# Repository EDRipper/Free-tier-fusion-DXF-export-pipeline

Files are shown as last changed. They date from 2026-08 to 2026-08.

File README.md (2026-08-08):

# Free-tier Fusion DXF export pipeline

Turn a Fusion 360 **Personal** design into **scaled, hole-corrected, nested, laser-ready cut sheets +
a BOM** — precisely and reproducibly — even though Fusion Personal won't export DXF from the File menu.

Strandbeest walking — Fusion motion study

*The mechanism this pipeline cuts parts for — gear-driven, three leg-racks phased 120° apart, one hand
crank. ([full-res MP4](video/beest_walk.mp4))*

---

## Why this exists — the Strandbeest workshop

This drives a real event: a **2-day hackathon in The Hague** where **30 people (six teams of five)**
each build a **waist-height, hand-cranked walking [Strandbeest](https://en.wikipedia.org/wiki/Jansen%27s_linkage)**
out of flat-cut plywood.

The animation above is the Fusion 360 model. The catch: it's designed at desktop scale with 4 mm
holes, and **Fusion Personal can't export DXF from the menu.** To turn one CAD model into six cuttable
kits you have to:

1. get every flat part out of Fusion as a precise DXF (Fusion Personal *can* do this via the sketch/API — this automates it),
2. **scale** the whole thing up to ~1 m,
3. resize each hole to a **real bearing/rod** — *not* by scaling it (a 4 mm hole must become a **13 mm
   bearing seat**, not a 24 mm one), but by setting it to the hardware size,
4. **nest** the parts onto plywood sheets and **label** each one,
5. spit out a **shopping list**.

That's this repo, end to end. Everything is Snijlab-ready (cut on [Snijlab](https://snijlab.nl):
blue = cut, red = engrave, 1200×1200 mm, DXF R2004, kerf-compensated).

**One complete beest** (start here) → [`nested_1kit/`](nested_1kit): three sheets,
[sheet_01](nested_1kit/sheet_01.dxf) · [sheet_02](nested_1kit/sheet_02.dxf) · [sheet_03](nested_1kit/sheet_03.dxf).

**All six kits** → [`output/demo/`](output/demo): 13 laser-ready sheets + a
[BOM with purchase links](output/demo/BOM.md). Read [`BUILD_RISKS.md`](BUILD_RISKS.md) before cutting.

### How the beest maps to the pipeline
| | |
|---|---|
| **Legs** | 6 (three racks × mirror pairs) → 8 unique links, 6 of each per kit |
| **Drive** | 3:4 reduction (12T pinion → 16T driven), crank pins phased 120°, hand-cranked |
| **Pivots** | M6 bolt through an **F686** bearing in every rotating link hole (13 mm seat), nyloc-capped |
| **Crankshaft** | **12 mm rod in 6001 bearings** (28 mm seats), supported at each rack level |
| **Scale** | ×6 → ~waist height; holes fixed to hardware (13 / 28 / 12 / 6 mm), independent of scale |

---

## What the pipeline does
**Stage A** (inside Fusion) — projects each flat component's face to a DXF at true 1:1 mm + a parts
manifest. **Stages B–D** (`pack_dxf.py`) — scale to build size, set each hole to its real hardware
diameter (only the 4 mm through-holes are treated as holes, so intentional larger holes survive),
nest all copies onto sheets with rectpack, etch each part's name on a `LABEL` layer, and write the BOM.
Geometry is never redrawn — only exact affine transforms — so fits are preserved.

## Setup (once)
```bash
py -m pip install ezdxf rectpack
```

## Run
```bash
# Stage A — inside Fusion: Utilities > ADD-INS > Scripts > run fusion_export_dxf.py
#   -> parts_raw/<part>.dxf (1:1 mm) + parts_raw/parts_manifest.csv

# Stages B-D:
py pack_dxf.py            # -> nested/sheet_XX.dxf + BOM.csv (+ BOM.md by hand)
```
No Fusion? `py make_test_parts.py && py pack_dxf.py` runs it on synthetic parts.

## Configure — `config.json`
| key | meaning |
|---|---|
| `scale` | master build scale = `target_leg_mm / current_leg_mm`. Applied to geometry only. |
| `kits` | how many kits to nest (6). |
| `sheet_w_mm`, `sheet_h_mm` | sheet size (2440×1220 = full NL berken-multiplex sheet). |
| `default_hole_mm` | size every through-hole becomes unless overridden (13 = F686 pivot). **Not scaled.** |
| `hole_source_dia_mm` | only circles this size (4 mm) are treated as holes; bigger circles are left as outline. |
| `part_hole_overrides` | per-part hole size; per-hole roles go in `parts_raw/hole_roles.csv` (part,cx,cy,dia). |
| `hardware_per_kit` | fastener counts → the BOM ×kits. |

## The key idea: size and holes are decoupled
- **Scale** stretches link *lengths* to make the beest big.
- **Hole diameters** are fixed to real hardware and are **never** scaled — a 13 mm bearing seat stays
  13 mm whether the beest is knee- or waist-height. `hole_roles.csv` assigns bearing vs friction per hole.

## After nesting
- Sheets are Snijlab-ready: **blue** (layer `cut`, RGB 0,0,255) = cut through, **red** (layer
  `line engraving`, RGB 255,0,0) = engrave. Check the uploader preview matches before paying.
- Push `parts_processed/*.dxf` through **Deepnest** for tighter true-shape nesting if you want fewer sheets.
- **Cut a fit-test coupon + one prototype beest first** to dial in kerf before committing all kits.

## Files
- `fusion_export_dxf.py` — Stage A (runs in Fusion). · `fusion_walk_frames.py` — captures the walk animation.
- `pack_dxf.py` — Stages B–D. · `config.json` / `parts_raw/hole_roles.csv` — the knobs.
- `output/demo/` — final sheets + BOM. · `input/demo/parts_raw/` — the real extracted parts.

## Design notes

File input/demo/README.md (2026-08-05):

# Demo input

Two forms of the strandbeest input:

- **`parts_raw/`** — the **12 real flat parts** exported from Fusion by `fusion_export_dxf.py`
  (Stage A): 8 leg links, 2 gears, 2 spacer plates, each a clean 1:1 mm outline + holes, plus
  `parts_manifest.csv`. **This is the directly runnable pipeline input** — point `config.json`'s
  `parts_dir` at it and run `py ../../pack_dxf.py` to reproduce the sheets in
  [`../../output/demo`](../../output/demo).

- **`beest-fusion-cache-backup.zip`** — the upstream Fusion source (assembly + all component
  `.f3d` cache files) the parts were exported from. Archival; raw cache files don't open standalone
  (a `.f3z` export is the portable format). Open the design in Fusion and run Stage A to regenerate
  `parts_raw/` yourself.

Round hardware (rods, pins, bearings, the crank) is intentionally **not** here — those are bought,
not cut.

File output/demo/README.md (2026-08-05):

# Demo output — real nested cut sheets + BOM

Generated by the pipeline from the **real** strandbeest parts in
[`../../input/demo/parts_raw`](../../input/demo/parts_raw):

- `sheet_01.dxf … sheet_09.dxf` — the nested cut sheets (2440×1220 mm), ready for a laser/CNC.
- `sheet_01.svg … sheet_09.svg` — the same, rendered for quick viewing.
- `BOM.csv` — cut-part quantities (×10 kits) + hardware list.

**How it was made:**
```bash
py pack_dxf.py     # with config.json: scale 6.0, 10 kits, 2440x1220 sheets
```
590 parts (12 unique × 10 kits) nested onto 9 sheets. Holes reset to real hardware sizes —
**6.5 mm** pivots and **8 mm** gear bores — independently of the ×6 scale.

The `scale: 6.0` here is a representative value (~hip-height beest). Set it to
`target_leg_mm / current_leg_mm` for your final build size and re-run.

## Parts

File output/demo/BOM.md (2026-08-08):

# Bill of Materials — 6 strandbeest kits

Uniform **8 mm** hardware system: **two hole sizes only** — 22 mm (608 bearing seat) and 8 mm
(M8 rod / friction). Prices are rough EUR estimates; per-kit × 6. Links are Amazon.nl searches (NL).

## Cut parts
13 unique parts, nested onto **13 sheets** of **9 mm birch plywood** (berken multiplex,
**1200×1200 mm** — Snijlab's birch stock size). DXFs: `sheet_01.dxf … sheet_13.dxf`, already
Snijlab-ready: **cut = blue** (layer `cut`, RGB 0,0,255), **engrave = red** (layer `line engraving`,
RGB 255,0,0), text converted to outlines, DXF R2004, mm. One whole beest spans ~3 sheets:
`../nested_1kit/`.

| Item | Qty | Source |
|---|---|---|
| 9 mm birch plywood, 1200×1200 sheet | 13 | [Snijlab birch ply (supplies + laser-cuts)](https://snijlab.nl/en/products/birch-plywood) · [GAMMA berken multiplex](https://www.gamma.nl/assortiment/zoeken?text=berken%20multiplex) |

## Hardware

Bearings are used **only on the crankshaft** (where continuous rotation earns them). Leg pivots are
plain **M8 bolt + nylon washers** running in 9 mm clearance holes — the friction math shows this is
easily hand-crankable (~0.4 kgf at the crank), and it avoids the "bearing works loose in plywood"
problem. This drops bearings from 606 to **30** — see `../BUILD_RISKS.md` (R4).

| Item | Size | Per kit | ×6 | ~€ total | Buy |
|---|---|---|---|---|---|
| **608ZZ** bearing — crankshaft supports only | 8×22×7 mm | 5 | **30** | ~€14 | [amazon.nl](https://www.amazon.nl/s?k=608zz+lager) |
| **M8 bolts** — leg pivot pins (links pivot on the shank) | 30–50 mm | 45 | **270** | ~€55 | [amazon.nl](https://www.amazon.nl/s?k=M8+bout+RVS) |
| **M8 nyloc** nuts | M8 | 45 | **270** | ~€22 | [amazon.nl](https://www.amazon.nl/s?k=M8+zelfborgende+moer) |
| **M8 nylon washers** — between every pivoting face | M8 | 120 | **720** | ~€22 | [amazon.nl](https://www.amazon.nl/s?k=M8+nylon+ring) |
| **8 mm steel rod** — crankshaft, crank pins, fixed shafts, handle | ⌀8 mm | 8 | **48** | ~€30 | [amazon.nl](https://www.amazon.nl/s?k=stalen+staf+8mm) |
| Crank handle | (cut part) | 1 | 6 | — | in the cut sheets |

**Hardware subtotal ≈ €145** (was ~€360 — dropping the leg-pivot bearings saves ~€215). Plywood/
cutting ≈ €300–480 (now 13× 1200×1200 sheets). **Rough total: €450–650 for all 6 kits.**

> Anti-bind tip: so beginners can't crush a pivot by over-tightening the nyloc, add a short M8 nylon
> spacer/bushing (or a shoulder bolt) sized to the link-stack length inside each pivot — the nut then
> bottoms out and the links stay free. Nylon washers between faces cut friction further.

## Hole roles — three sizes
- **22 mm** (608 bearing seat, ×30 total): crankshaft supports only — frame-spacer crankshaft hole,
  spacer bearing hole.
- **9 mm** (M8 pivot clearance): every leg-link pivot hole — links rotate freely on the bolt shank.
- **8 mm** (M8 rod, friction/press): frame-spacer fixed-shaft holes · spacer friction hole · gear
  centres · driven-gear crank pin · crank handle · crank crankshaft mount.

## The system
- **Crankshaft:** 8 mm rod in 608 bearings (22 mm seats), supported at each frame rack.
- **Leg pivots:** M8 bolt through 9 mm clearance holes, nyloc-capped, nylon washers between faces —
  no bearings, hand-crankable, nothing to work loose.
- **Friction holes** (fixed shafts, gear bores, crank pins/mount, handle): 8 mm, press-fit on the rod.

_Hole sizes are drawn kerf-compensated (−0.2 mm); confirm the exact fit with a coupon before the full cut._

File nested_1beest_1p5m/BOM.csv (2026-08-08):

CUT PARTS | per_kit | kits | total | hole_mm | notes
crank | 1 | 1 | 1 | per-hole | 3mm(model), x9.0
driving gear | 3 | 1 | 3 | per-hole | 5mm(model), x9.0
driven gear | 3 | 1 | 3 | per-hole | 5mm(model), x9.0
frame spacer | 2 | 1 | 2 | per-hole | 3mm(model), x9.0
spacer | 3 | 1 | 3 | per-hole | 3mm(model), x9.0
Links h,i,g | 12 | 1 | 12 | 9 | 3mm(model), x9.0
LinkC | 6 | 1 | 6 | 9 | 3mm(model), x9.0
LinkD | 6 | 1 | 6 | 9 | 3mm(model), x9.0
LinkB | 6 | 1 | 6 | 9 | 3mm(model), x9.0
LinkE | 12 | 1 | 12 | 9 | 3mm(model), x9.0
LinkF | 6 | 1 | 6 | 9 | 3mm(model), x9.0
LinkK | 12 | 1 | 12 | 9 | 3mm(model), x9.0
LinkJ | 12 | 1 | 12 | 9 | 3mm(model), x9.0
SHEETS |  |  | 7 |  | 1200x1200mm
HARDWARE | per_kit | kits | total
6900ZZ bearing (10x22x6) - central crankshaft supports (22mm seat = same as 608) | 5 | 1 | 5
10mm steel rod - central crankshaft (driven gear keyed to it) | 2 | 1 | 2
M8 bolt 30-50mm - leg pivot pins (links pivot on the shank, 9mm clearance holes) | 45 | 1 | 45
M8 nyloc nut | 45 | 1 | 45
nylon washer/spacer M8 - between every pivoting face | 120 | 1 | 120
8mm steel rod - 2 side fixed shafts + crank pins + gear/fixed fits + handle (cut to length) | 8 | 1 | 8
crank handle (cut part) | 1 | 1 | 1

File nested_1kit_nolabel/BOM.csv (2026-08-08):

CUT PARTS | per_kit | kits | total | hole_mm | notes
crank | 2 | 1 | 2 | per-hole | 3mm(model), x6.0
driving gear | 3 | 1 | 3 | per-hole | 5mm(model), x6.0
driven gear | 3 | 1 | 3 | per-hole | 5mm(model), x6.0
frame spacer | 2 | 1 | 2 | per-hole | 3mm(model), x6.0
spacer | 3 | 1 | 3 | per-hole | 3mm(model), x6.0
Links h,i,g | 6 | 1 | 6 | 9 | 3mm(model), x6.0
LinkC | 6 | 1 | 6 | 9 | 3mm(model), x6.0
LinkD | 6 | 1 | 6 | 9 | 3mm(model), x6.0
LinkB | 6 | 1 | 6 | 9 | 3mm(model), x6.0
LinkE | 6 | 1 | 6 | 9 | 3mm(model), x6.0
LinkF | 6 | 1 | 6 | 9 | 3mm(model), x6.0
LinkK | 6 | 1 | 6 | 9 | 3mm(model), x6.0
LinkJ | 6 | 1 | 6 | 9 | 3mm(model), x6.0
SHEETS |  |  | 3 |  | 1200x1200mm
HARDWARE | per_kit | kits | total
608ZZ bearing (8x22x7) - crankshaft supports only | 5 | 1 | 5
M8 bolt 30-50mm - leg pivot pins (links pivot on the shank, 9mm clearance holes) | 45 | 1 | 45
M8 nyloc nut | 45 | 1 | 45
nylon washer/spacer M8 - between every pivoting face | 120 | 1 | 120
8mm steel rod - crankshaft + crank pins + fixed shafts + handle (cut to length) | 8 | 1 | 8
crank handle (cut part) | 1 | 1 | 1

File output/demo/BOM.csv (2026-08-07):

CUT PARTS | per_kit | kits | total | hole_mm | notes
crank | 2 | 6 | 12 | per-hole | 3mm(model), x6.0
driving gear | 3 | 6 | 18 | per-hole | 5mm(model), x6.0
driven gear | 3 | 6 | 18 | per-hole | 5mm(model), x6.0
frame spacer | 2 | 6 | 12 | per-hole | 3mm(model), x6.0
spacer | 3 | 6 | 18 | per-hole | 3mm(model), x6.0
Links h,i,g | 6 | 6 | 36 | 22 | 3mm(model), x6.0
LinkC | 6 | 6 | 36 | 22 | 3mm(model), x6.0
LinkD | 6 | 6 | 36 | 22 | 3mm(model), x6.0
LinkB | 6 | 6 | 36 | 22 | 3mm(model), x6.0
LinkE | 6 | 6 | 36 | 22 | 3mm(model), x6.0
LinkF | 6 | 6 | 36 | 22 | 3mm(model), x6.0
LinkK | 6 | 6 | 36 | 22 | 3mm(model), x6.0
LinkJ | 6 | 6 | 36 | 22 | 3mm(model), x6.0
SHEETS |  |  | 6 |  | 2440x1220mm
HARDWARE | per_kit | kits | total
608ZZ bearing (8x22x7) - all pivots + shaft supports | 96 | 6 | 576
M8 bolt 30-50mm - pivot pins | 45 | 6 | 270
M8 nyloc nut | 45 | 6 | 270
nylon washer/spacer M8 | 120 | 6 | 720
8mm steel rod - crankshaft + crank pins + fixed shafts + handle (cut to length) | 8 | 6 | 48
crank handle (cut part) | 1 | 6 | 6

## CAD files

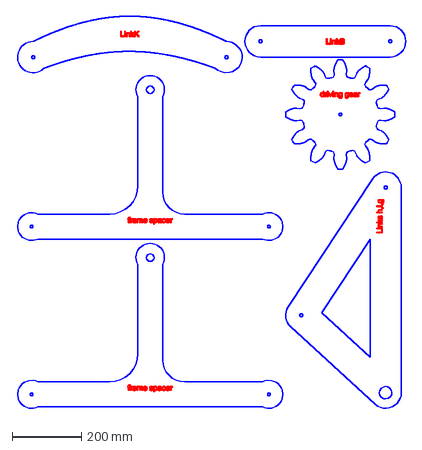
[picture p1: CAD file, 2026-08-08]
nested_1beest_1p5m/sheet_01.dxf
1122.4 x 1134.2 mm

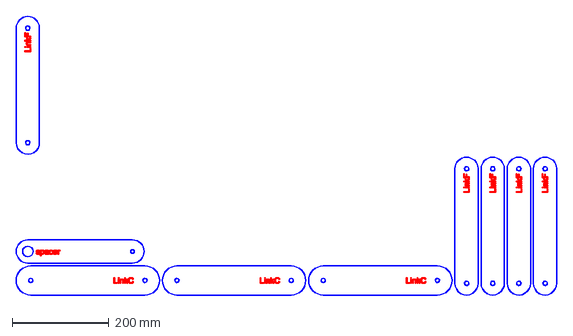
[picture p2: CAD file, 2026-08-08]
nested_1kit/sheet_03.dxf
1115.7 x 576.1 mm

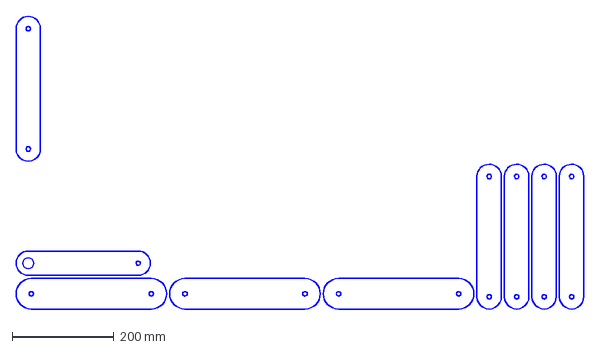
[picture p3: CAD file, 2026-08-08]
nested_1kit_nolabel/sheet_03.dxf
1115.7 x 576.1 mm

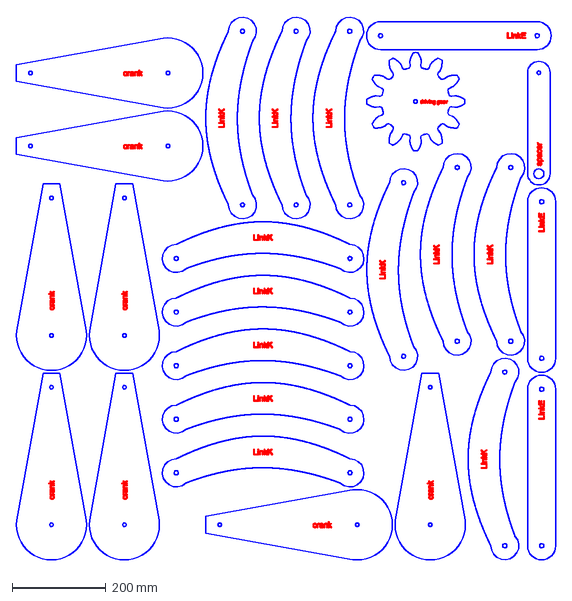
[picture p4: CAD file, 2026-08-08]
output/demo/sheet_07.dxf
1153.2 x 1165.3 mm

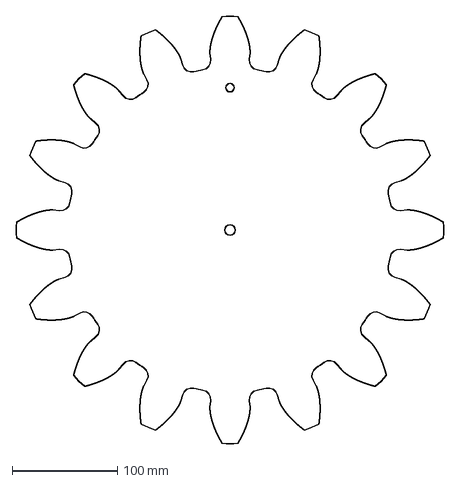
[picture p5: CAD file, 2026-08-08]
parts_processed_1p5m/Spur Gear 12 teeth.dxf
405.1 x 405.1 mm

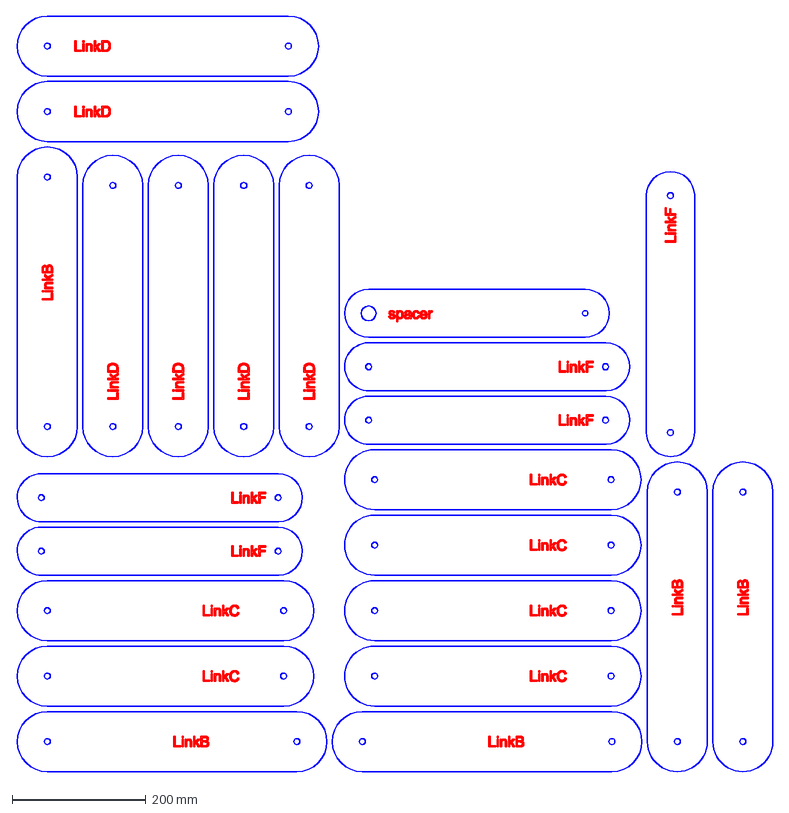
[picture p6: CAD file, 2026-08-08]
nested_1beest_1p5m/sheet_07.dxf
1132.7 x 1133.0 mm

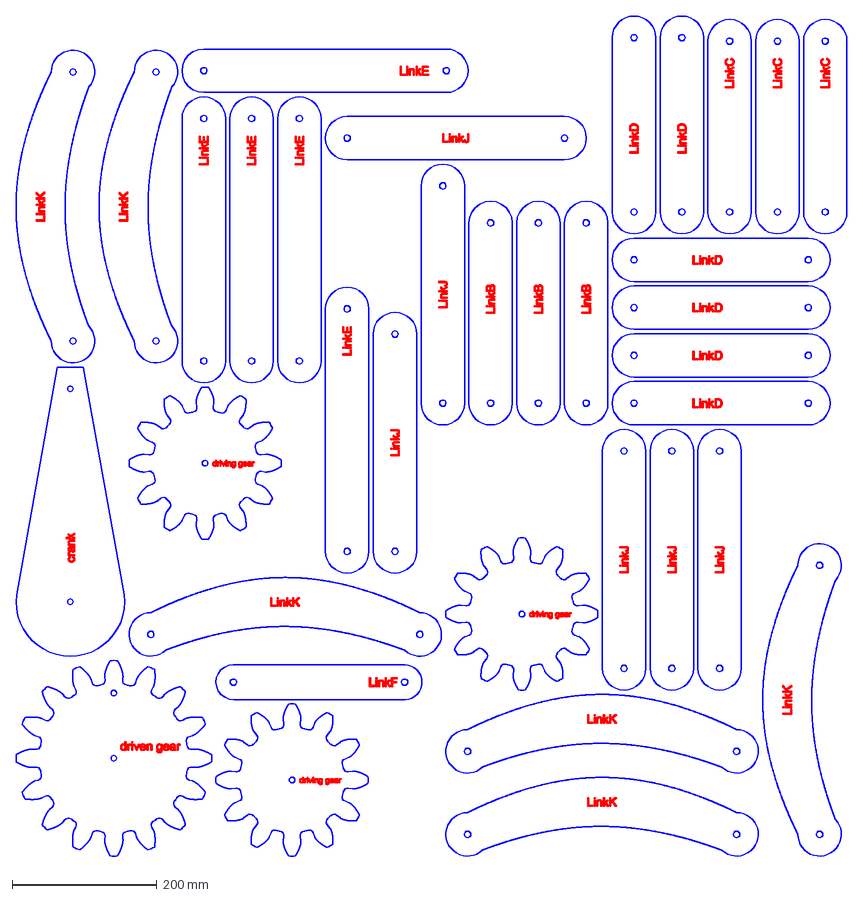
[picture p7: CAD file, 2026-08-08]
nested_1kit/sheet_02.dxf
1147.2 x 1162.5 mm

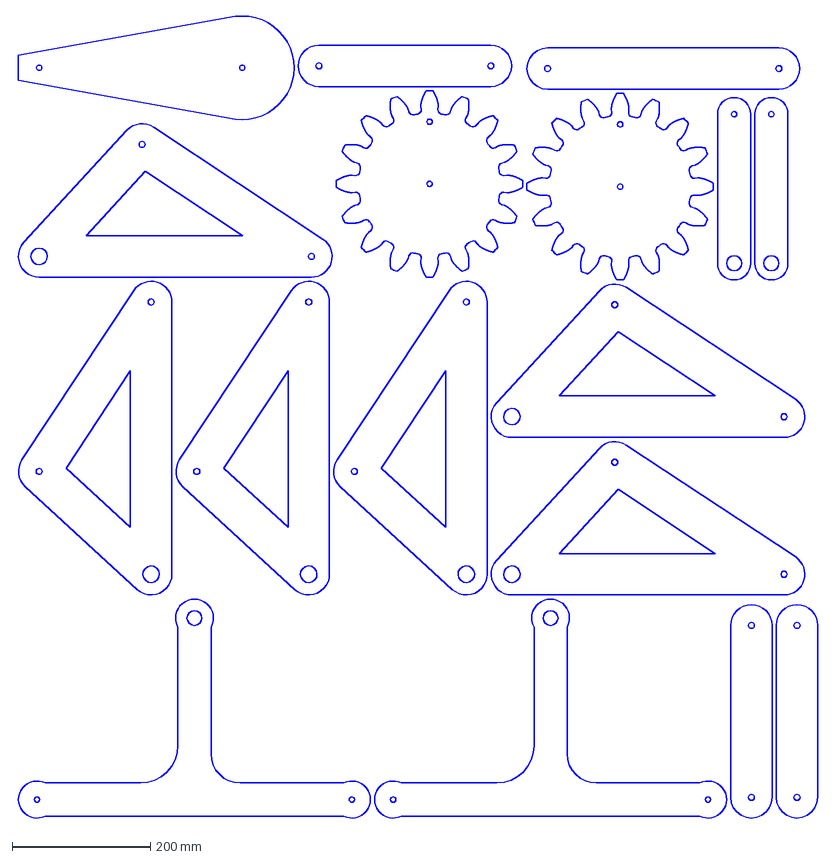
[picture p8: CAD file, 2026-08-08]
nested_1kit_nolabel/sheet_01.dxf
1160.5 x 1164.2 mm

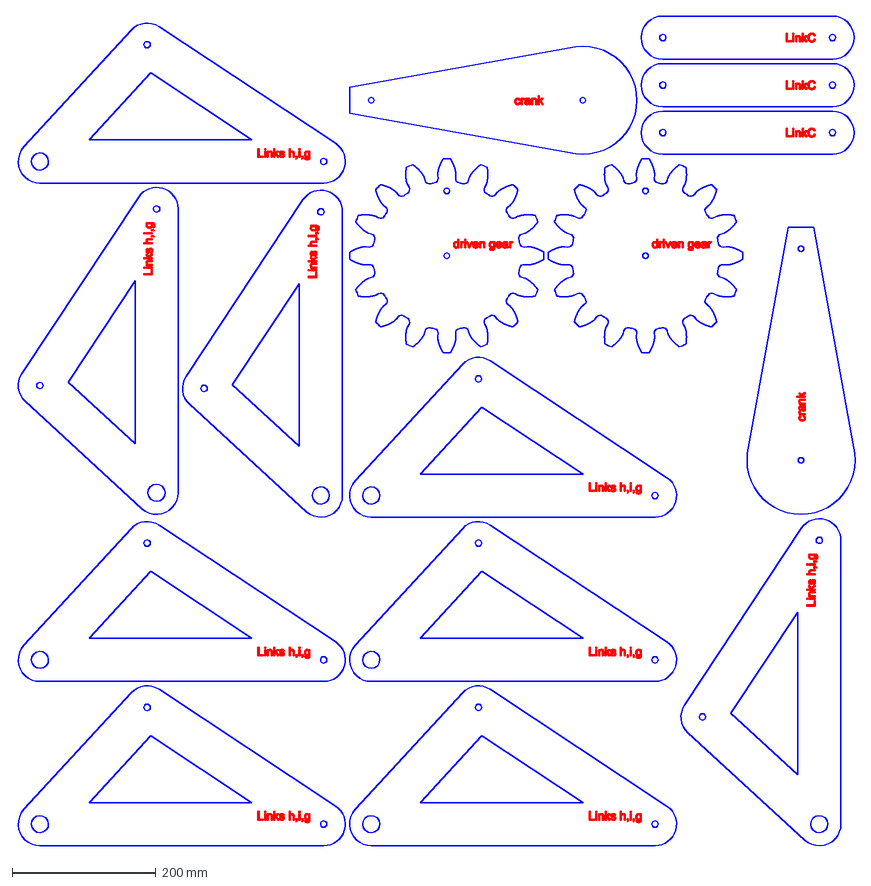
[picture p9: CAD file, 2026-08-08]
output/demo/sheet_05.dxf
1165.4 x 1152.8 mm

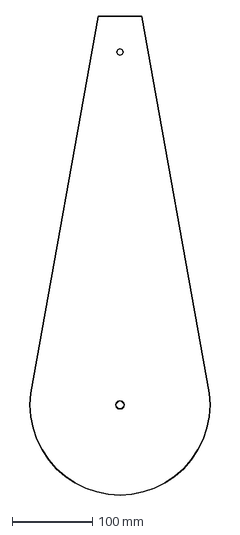
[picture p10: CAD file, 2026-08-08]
parts_processed_1p5m/crank.dxf
225.0 x 598.5 mm

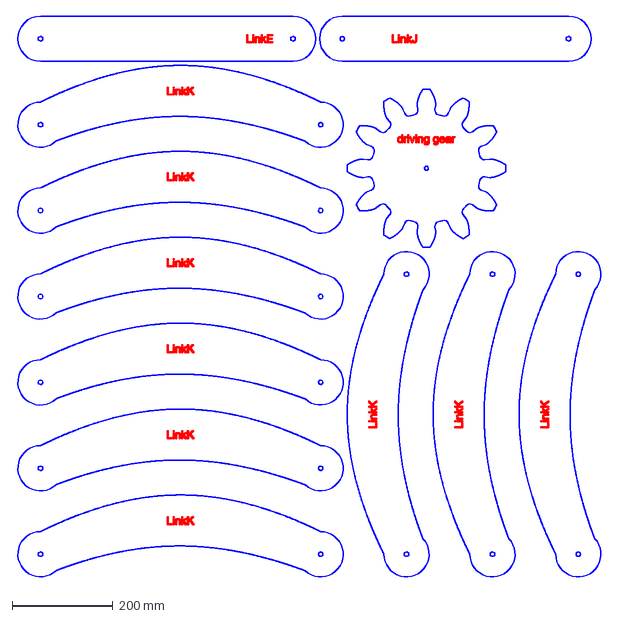
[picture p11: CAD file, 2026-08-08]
nested_1beest_1p5m/sheet_05.dxf
1167.5 x 1119.3 mm

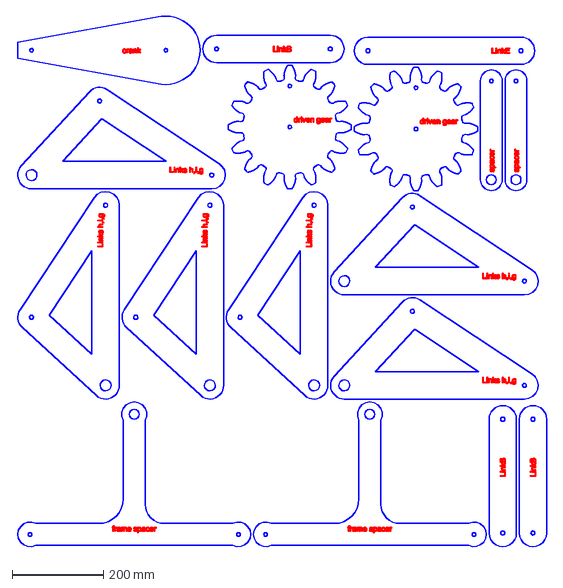
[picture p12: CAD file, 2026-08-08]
nested_1kit/sheet_01.dxf
1160.5 x 1164.2 mm

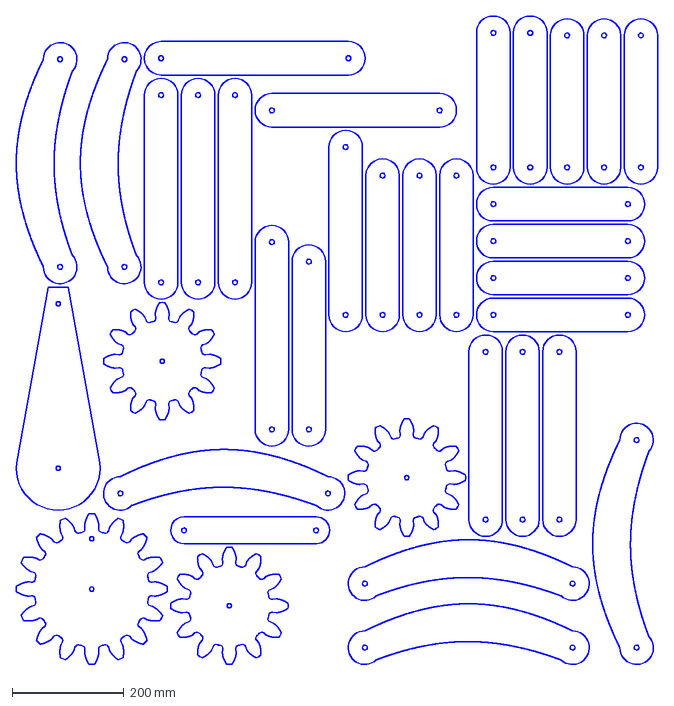
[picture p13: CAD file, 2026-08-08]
nested_1kit_nolabel/sheet_02.dxf
1147.2 x 1162.5 mm

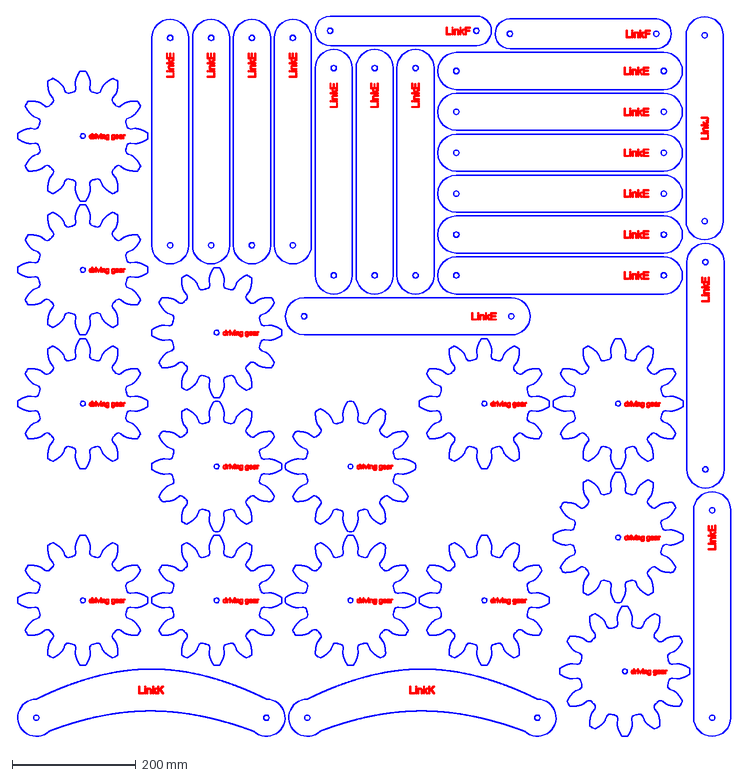
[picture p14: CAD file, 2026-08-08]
output/demo/sheet_09.dxf
1153.3 x 1165.5 mm

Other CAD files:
parts_processed_1p5m/spacer.dxf
nested_1beest_1p5m/sheet_06.dxf
output/demo/sheet_11.dxf
parts_processed_1p5m/LinkD.dxf
nested_1beest_1p5m/sheet_02.dxf
nested_1beest_1p5m/sheet_03.dxf
nested_1beest_1p5m/sheet_04.dxf
output/demo/sheet_01.dxf
output/demo/sheet_02.dxf
output/demo/sheet_03.dxf
output/demo/sheet_04.dxf
output/demo/sheet_06.dxf
output/demo/sheet_08.dxf
output/demo/sheet_10.dxf
output/demo/sheet_12.dxf
output/demo/sheet_13.dxf
parts_processed_1p5m/Component19.dxf
parts_processed_1p5m/LinkB.dxf
parts_processed_1p5m/LinkC.dxf
parts_processed_1p5m/LinkE.dxf
parts_processed_1p5m/LinkF.dxf
parts_processed_1p5m/LinkJ.dxf
parts_processed_1p5m/LinkK.dxf
parts_processed_1p5m/driving gear.dxf
parts_processed_1p5m/frame spacer.dxf

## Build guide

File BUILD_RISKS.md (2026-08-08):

# Build Risk Review — before cutting 6 workshop kits

A pre-flight review done before committing plywood + hardware to a 30-person, 2-day workshop.
Ordered by severity. Numbers come from an audit of the actual cut files (`parts_processed/`,
`nested*/`) plus external research (sources at the bottom).

**Golden rule:** cut a fit-test coupon and one full prototype kit, assemble it, and confirm it
walks — *before* cutting the other five. Every item below is far cheaper to fix at coupon stage.

---

## ✅ Fixed in the pipeline (commit history)
- **R1 (sheet size):** re-nested to **1200 × 1200 mm** (Snijlab birch stock).
- **R2 (colours/format):** cut → blue `cut` layer RGB(0,0,255); labels → red `line engraving` layer
  RGB(255,0,0); label text converted to **outline polylines** (no TEXT); saved as **DXF R2004**, mm.
- **R3 (kerf):** `kerf_mm` (default 0.2) now shrinks every hole by one kerf — still confirm the exact
  value with a fit-test coupon.
- **R4 (bearings):** dropped to **crankshaft-only** — 606 → **30** bearings. Leg pivots are now M8
  bolt + nylon washer in **9 mm clearance holes** (friction math: ~0.4 kgf at the crank). Saves ~€215
  and removes the plywood-bearing-retention problem entirely.
- **R8 (Component19):** confirmed by the user — "Links h,i,g" **is one physical part**. ✅ (Gear-mesh
  spacing still worth an eyeball in the assembly.)

Remaining open items are design/process decisions (R5 prototype, R6 doubling, R7 friction, R9–R13).

---

## 🔴 High severity — fix before cutting

### R1. Sheet size doesn't match Snijlab's material/bed  — ✅ done (re-nested 1200×1200)
- **Evidence:** we nest onto **2440 × 1220 mm**. Snijlab's birch plywood comes on **1200 × 1200 mm**
  sheets; their standard laser bed is **1200 × 600**, large-format up to **2400 × 1200**. Our sheet
  is bigger than *all* of those (even 40 mm over the large-format bed).
- **Why it bites:** the current nesting is un-cuttable at Snijlab as-is; parts near the sheet edge
  fall outside their material.
- **Fix:** re-nest to Snijlab's real stock — **1200 × 1200 mm** (safe, guaranteed in 9 mm birch).
  The longest part is only 510 mm, so it nests fine; you just get more, smaller sheets. One-line
  config change (`sheet_w_mm`/`sheet_h_mm`) + re-run. *(Alternatively confirm 9 mm birch is offered
  on the 2400 × 1200 large-format service and nest to ≤2380 × 1180.)*

### R2. Cut/engrave colours + file format don't match Snijlab's spec
- **Evidence:** our DXFs use layer `0` = cut in **black** and `LABEL` = **red** text. Snijlab reads
  **cut = blue RGB(0,0,255)**, **line-engrave = red RGB(255,0,0)**, plane-engrave = magenta, in
  **RGB** mode; grey is ignored. It also wants **DXF 2004**, **mm, 1:1**, and **text converted to
  outlines**.
- **Why it bites:** our black cut lines may be read as "ignore," and TEXT labels may not import.
  Our red labels happen to match their line-engrave red — but cut is the problem.
- **Fix (pipeline):** remap cut geometry → blue `cut` layer RGB(0,0,255); labels → red
  `line engraving` layer RGB(255,0,0); **convert label text to outline paths**; save as DXF R2004.
  All doable in `pack_dxf.py`. Then confirm against Snijlab's upload preview (it shows exactly what
  will be produced).

### R3. Kerf is not compensated — every fit is affected
- **Evidence:** no kerf offset in `config.json`/`pack_dxf.py`; holes drawn at nominal.
- **Why it bites:** the laser removes ~0.15–0.2 mm and interior holes cut ~one kerf **oversize** →
  8 mm friction holes cut ~8.2 mm (won't grip the rod), 22 mm bearing seats cut ~22.2 mm (608 drops
  in loose).
- **Fix:** shrink hole diameters ~one kerf (draw ~7.8–8.0 mm for the rod fit, ~21.8–22.0 mm for the
  bearing seat), then **verify with a fit-test ladder** on Snijlab's machine + the actual ply batch
  (seats at 21.9/22.0/22.1/22.2; friction at 7.8/7.9/8.0/8.1). Measure real ply thickness first —
  "9 mm" birch is often 8.5–9.2 mm.

### R4. 606 bearings (101/kit) — over-engineered, costly, hard to retain
- **Evidence (audit):** every leg-link hole is a 22 mm 608 seat → **101/kit × 6 = 606 bearings**
  (~€230–300), plus 20 friction holes/kit.
- **Why it bites:** a 22 mm press-fit in 9 mm ply has little grip and **plywood creeps → bearings
  work loose/fall out**; the 7 mm bearing is narrower than the 9 mm ply (walks axially); adjacent
  outer races in a stacked pivot can rub; and pressing 600+ bearings with beginners in 2 days is a
  huge time sink.
- **Fix — pick one:**
  1. **Bearings only where they earn it** (recommended, = original plan): crankshaft (+ optional
     gear shafts) only; leg pivots become **M8 bolt + PTFE/nylon washer + nyloc**. ~101 → ~4–8
     bearings/kit. Hand-crank speeds don't need a bearing at every pivot.
  2. **Keep them but retain properly:** epoxy/retaining compound in each seat and/or **laminate two
     ply layers** for a deeper shouldered bore (also fixes R6).

### R5. No prototype and no fit coupon cut yet
- **Fix — sequence:** (1) fit-test coupon → set kerf; (2) cut **one full kit**; (3) assemble &
  hand-crank to confirm it walks; (4) only then cut the other 5.

---

## 🟠 Medium severity

### R6. Slender single-layer links rack out of plane
- **Evidence (audit):** longest links L/W ≈ 6.6 (LinkE 395×60, LinkJ 360×60, LinkF 284×48) in single
  9 mm ply. Walls around holes are healthy (≥13 mm) — the issue is sideways floppiness, not snapping.
- **Why it bites:** deflection ∝ length³; single flat bars flex out of the kinematic plane, the foot
  leaves its plane, stride shrinks, it wobbles. Joint slop (~0.1 mm/joint) also sums to several mm at
  the foot across an 8-bar leg.
- **Fix:** **double-up (laminate) the long links** with internal spacers, and box/triangulate the
  central frame — standard practice at ~1 m. Doubling also deepens the bearing bores (R4 option 2).

### R7. Friction & hand-crank effort
- **Why it bites:** a 6-leg, ~130-pivot machine is **friction-dominated**; torque accumulates and can
  make it hard to crank.
- **Fix:** PTFE/thrust washers between moving faces, smooth shoulder-bolt or bushed pivots, nylocs
  snug-not-tight, and a generous crank-handle radius. The existing gear reduction helps — keep it.

### R8. Verify in the Fusion assembly (not visible from flat parts)
- **Gear mesh centre distance:** the two gear shafts must sit at the correct pitch spacing or teeth
  won't mesh (tooth ratio ~3:4 is fine; confirm the shaft-hole spacing).
- **"Component19 / Links h,i,g":** one 454×222 mm plate with only **2 holes** — if that name means
  three separate links merged into one Fusion component, cutting it as a single plate is wrong.
  Confirm it's genuinely one physical part.

### R9. Crankshaft — single 8 mm rod driving 6 legs
- **Why it bites:** wind-up/deflection across the width robs motion from far legs.
- **Fix:** bearing-support the crankshaft at every rack (frame spacers); keep spans short; step up
  rod diameter if whippy on the prototype.

---

## 🟡 Lower severity / logistics

### R10. Feet slip on smooth floors
- Strandbeests walk in place on smooth surfaces — the pointed feet need grip. **Add rubber foot
  caps / textured tips** for a hard workshop floor.

### R11. Phasing errors bind or limp
- Legs are clocked on the crankshaft (racks phased 120°). Verify each rack's crank throw is set to
  the intended offset **before final tightening** — if it hops/rocks, check phasing first.

### R12. Weight & tipping
- ~13 kg/kit raw part area (bbox upper bound; real ~8–9 kg cut); ~98 kg ply across 6 sheets (fewer
  per sheet once re-nested to 1200×1200). Ensure a stable stance; it's a heavy machine.

### R13. Assembly guide for beginners
- 6 legs × 8 links × several pivots is a lot of steps. Engraved labels help; add a printed manual,
  alignment jigs, and pre-bagged hardware per team.

---

## Snijlab specifics (confirmed from their design-rules pages)
- **Formats:** DWG, DXF, AI, PDF. Draw 1:1, **mm**. Export **DXF/DWG 2004 "natural."** Convert text
  & fills to outlines; strip dimensions/frames/centrelines.
- **Cut vs engrave (RGB):** cut-through = **blue 0,0,255**; line-engrave = **red 255,0,0**;
  plane-engrave = **magenta 255,0,255** (closed paths). RGB mode only (CMYK misreads). Grey = ignored.
  Line thickness ~0.2 mm. Upload preview shows the final result.
- **Sizes:** standard bed 1200×600; large-format up to 2400×1200.
- **9 mm birch ("berken multiplex"):** stocked & cut, B/B FSC; birch sheet **1200×1200 mm**; from ~€15.
- **Pricing:** instant automated quote from the drawing (cut length/area/part count) × qty × material
  × delivery speed — not flat per-sheet. Get the live quote.
- **Lead time:** you choose it; Express = order before 12:00, next-day.

---

## Sources
- Kerf-aware hole sizing (IDeATe/CMU) — https://courses.ideate.cmu.edu/16-375/f2025/text/mechanism/bearing-demos.html
- Plywood kerf — https://www.1laser.com/blogs/topic/laser-cutting-plywood · https://cutlasercut.com/drawing-resources/expert-tips/laser-kerf/
- Wall/edge margins — https://sendcutsend.com/blog/basic-tolerances-and-cut-feature-relationships/
- Press-fit retention in wood (epoxy/Loctite) — https://www.homemodelenginemachinist.com/threads/what-size-hole-for-press-fit.828/
- Strandbeest build problems (slop, doubled links, friction, feet) — https://makezine.com/article/drones-vehicles/6-common-problems-to-avoid-when-building-a-strandbeest/
- DIY Walkers / Burns build (phasing, feet) — https://www.diywalkers.com/strandbeest.html
- Plywood strandbeest build reference — https://www.nablu.com/2020/05/building-strandbeest.html
- Snijlab design rules — https://snijlab.nl/en/pages/drawing-rules · birch ply — https://snijlab.nl/en/products/birch-plywood

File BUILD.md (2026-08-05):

# Making it real — strandbeest kit build spec

Everything needed to turn the nested sheets in [`output/demo`](output/demo) into **6 hand-cranked,
waist-height walking strandbeest kits** (6 teams of 5, 2 days). Per-kit figures are in `BOM.csv`.

---

## 1. The pin joints (the core question)

Every leg joint is a **pivot**: links must rotate relative to each other around a shared pin.

**The joint stack (per pivot):**
- **One shared pin** = an **M6 bolt** (or 6 mm rod) through the aligned holes of every link at that pivot.
- **Rotation** = a **flanged ball bearing** seated in each rotating link's hole. The link spins on it.
- **The flange** sits against the plywood face and **stops the bearing pushing through**.
- **Retention** = **bolt head** one end + **M6 nyloc nut** the other = the caps that stop the pin
  sliding out. Snug, not clamped — bearings must still spin freely.
- **Spacing** = **nylon washers** between links so faces don't rub.

*Shared M6 pin · ball bearings spin · flanges + bolt-head/nyloc retain.* No press-fit on the links.

### Why ball bearings, not bushings
~40 pivots per beest, hand-cranked (no motor to muscle through stiction). Bushings are *sliding*
friction (μ≈0.1–0.2, sticky at startup); ball bearings are *rolling* (μ≈0.002) — ~20–100× less drag,
compounded across 40 joints, and worse for bushings at waist-scale loads. Ball bearings it is.

### Bearing vs friction, per hole — NOT YET CONFIRMED
The extracted outlines carry no signal for this (every hole was 4 mm), so the current sizes are a
**guess by part type**, not derived from the mechanism. The reliable source is the **Fusion joints**:
a Revolute joint at a hole ⇒ it rotates ⇒ bearing seat; a Rigid joint ⇒ friction fit. Until the
exporter reads the joints (or you confirm per part), treat this table as provisional:

- Leg-link holes → 13 mm ball-bearing seats *(guess: assumes both links rotate at every pivot)*
- Gear centres → 8 mm friction fit onto the shaft *(guess)*
- Frame-spacer holes → 22 mm 608 seats *(guess)*
- Spacer holes → 8 mm shaft *(guess)*

Per-hole truth can be supplied via `parts_raw/hole_roles.csv` (part, cx, cy, dia) — which the joint
exporter will generate.

### Optional saving (same smoothness)
Fixing one link per pivot to the pin (only its neighbour rotates on a bearing) **halves** the bearing
count to ~45/kit with *identical* rolling friction. Needs per-hole role assignment, so do it once the
assembly order is locked; the simple "bearing in every hole" version below is foolproof for the workshop.

---

## 2. Bearings & hardware (real parts, 6 kits)

| Role | Part | Size (bore×OD×W) | Hole seat | Qty (6 kits) | Source |
|---|---|---|---|---|---|
| Leg pivots | **F686ZZ** flanged ball bearing | 6×13×5 | 13 mm | ~540 | Amazon.nl / bearing shop, bulk |
| Crankshaft | **608ZZ** skate bearing | 8×22×7 | 22 mm | ~36 | Amazon.nl ~€6.5/10 |
| Pivot pins | **M6 bolts** 30–50 mm | — | 13 mm | ~270 | GAMMA/Hornbach/Praxis |
| Pin caps | **M6 nyloc nuts** | — | — | ~270 | DIY store |
| Spacing | **M6 nylon washers** | — | — | ~720 | DIY store |
| Shafts | **8 mm steel rod** — 1 crank/driving + 2 fixed-point shafts | — | 8/22 mm | 18 (3/kit) | DIY store |
| Crank handle | cut plywood part | — | — | 6 | (cut) |

Dutch terms: kogellager (bearing), bout (bolt), zelfborgende moer (nyloc), ring (washer),
draadeind (threaded rod), berken multiplex (birch ply).

---

## 3. Scale & size

- **`scale: 6.0`** → **~waist-height** (longest link ≈ 431 mm, full beest ≈ 0.9–1 m). The 13 mm
  bearing seats fit with big margin (they'd fit down to ~×2.5), so *size* sets the scale here.
- Retarget with **`scale = target_leg_mm / current_leg_mm`** — give me a leg height and I set it exactly.
- **Holes never scale** — fixed to hardware (13 / 8 / 22 mm) at any `scale`.

---

## 4. Material & cutting

- **9 mm birch multiplex** (berken multiplex), 2440×1220 sheets. One honest 9 mm stock throughout
  (2D outlines are thickness-agnostic; the model's 3/5 mm values are informational).
- **6 sheets for 6 kits** with the built-in bounding-box nester; **Deepnest** (true-shape) drops it to ~4.
- **Labels:** every part is etched with its name on the **`LABEL`** layer — set that layer to
  **score/engrave**, everything else to **cut**. Essential for 30 people sorting parts.
- **Cut a fit-test coupon first** (13 mm holes at nominal ±0.1/0.2 mm) to dial in kerf for a snug
  bearing press on the real machine + material.

---

## 5. Rough budget (6 kits, ball bearings)

| item | cost |
|---|---|
| Plywood (~6 sheets) | €300–480 |
| F686 pivot bearings (~540) | ~€216 |
| 608 + rod + misc | ~€65 |
| Bolts / nyloc / washers | ~€150 |
| **Total** | **~€730–910** |

Deepnest (fewer sheets) and the friction-fix optimization (half the bearings) pull it lower.

---

## 6. Build flow (2 days, 6 teams of 5)

1. **Pre-cut** all 6 sheets on FabLab Den Haag's CNC router *before* the event (30 people can't share one machine).
2. Day 1: each team assembles its beest's legs — press a bearing into each link hole, stack the links,
   run the M6 pin, washers between, nyloc to snug. Etched labels tell them which link is which.
3. Day 1 (parallel): build each crankshaft — 608 bearings in the frame plates, gears on the 8 mm shaft,
   crank handle on top.
4. Day 2: mount legs to the crank throws (120° phased), tune, hand-crank, walk.
5. **De-risk:** build ONE full kit as a prototype before cutting all six.

---

## 7. Confirm with me
- The two `*(assumed)*` hole roles (frame spacer, spacer) — their real job in the drivetrain.
- Final **leg height** → exact `scale`.
- The **`crank`** part still needs a clean re-export (its holes were on the wrong face).

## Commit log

2026-08-05 Free-tier Fusion DXF export pipeline: scale, hole-correct, nest, BOM
    Fusion Personal -> per-part DXF (Stage A script) -> ezdxf scale + hole-diameter
    correction -> rectpack nesting onto sheets -> BOM. Tested end-to-end on synthetic
    parts. Decouples build scale from hole diameters so hardware fits stay exact.
2026-08-05 Add demo input (Fusion source backup) and demo output (nested sheets + BOM)
    [BOM.csv, sheet_01.dxf, sheet_02.dxf]
2026-08-05 Stage A: auto-filter to flat plate-like parts only; self-clean temp sketches
2026-08-05 Real data: export 12 beest parts, nest to 9 sheets; fix pin false-positive + OneDrive path
    - Stage A: reject round pins (broad-face vs thickness ratio), resolve OneDrive-redirected Desktop
    - input/demo/parts_raw: 12 real extracted parts (runnable input)
    - output/demo: real nested sheets (9) + BOM from those parts
    - config: gear bores 8mm, links 6.5mm
    [BOM.csv, sheet_01.dxf, sheet_02.dxf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]
2026-08-05 Bearing-driven joints + part labels + BUILD.md
    - pivot holes = 13mm (F686 seat); gears 8mm; frame 22mm (608). Every part etched on LABEL layer.
    - BUILD.md: pin-joint scheme, bearing spec, scale, hole map, tiered cost, BOM, NL sourcing, build flow.
    - regenerated output/demo (9 labelled sheets + BOM).
    [BOM.csv, sheet_01.dxf, sheet_02.dxf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]
2026-08-05 6 kits (6 teams of 5); ball bearings at pivots (friction), not bushings
    - kits 10 -> 6: 354 parts on 6 sheets
    - BUILD.md: ball-bearing rationale (rolling vs sliding across ~40 pivots), recomputed BOM/budget/teams
    [BOM.csv, sheet_01.dxf, sheet_02.dxf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]
2026-08-05 Honesty + fixes: labels on solid material, hole roles marked GUESS, rod count 3/kit
    - labels now placed on widest solid region (verified on-material), not bbox centre
    - pack_dxf prints hole-role source (GUESS vs joints); supports parts_raw/hole_roles.csv per-hole
    - BUILD.md: hole roles flagged NOT CONFIRMED (need Fusion joints); shafts corrected to 3/kit
    [BOM.csv, sheet_01.dxf, sheet_02.dxf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]
2026-08-06 Final: real 13-part extraction, bearing/friction roles, BOM with purchase links
    - Stage A: face-projection (trimmed outlines) + full hole capture
    - pack_dxf: 'only 4mm circles are holes' rule (preserves crank's 25mm hole); per-hole roles via hole_roles.csv
    - hole_roles.csv: 13mm F686 pivots, 28mm 6001 crankshaft, 12mm gear bores, 6mm friction
    - output/demo: 6 final labelled nested sheets + BOM.csv + BOM.md (with Amazon.nl/Snijlab links)
    - input/demo/parts_raw: the 13 real parts + hole_roles
    - add walk-animation script; gitignore scratch dirs
    [BOM.csv, sheet_01.dxf, sheet_02.dxf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]
2026-08-06 Resolve 3 hole roles: crank handle 6mm, spacer bearing 28mm (12mm shaft); 6001 x6
    [BOM.csv, sheet_01.dxf, sheet_02.dxf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]
2026-08-06 Regenerate one-beest sheet (nested_1kit) with final hole roles
    [BOM.csv, sheet_01.dxf]
2026-08-07 README: embed walk video + explain the full Strandbeest workshop concept
    - walking GIF hero + MP4 link
    - 'Why this exists' section: 30-person Hague hackathon, 6 kits, Fusion->laser flow
    - beest->pipeline mapping table; updated config docs (kits 6, hole_roles.csv, 4mm rule)
2026-08-07 Uniform 8mm system: two hole sizes only (22mm 608 bearing / 8mm M8 friction)
    - hole_roles + config: 608 everywhere (22mm seats), 8mm rod/M8; drops F686/6001/12mm
    - BOM.md updated to the single-bearing single-rod kit
    - regenerate 6-kit + 1-kit sheets
    [BOM.csv, sheet_01.dxf, sheet_02.dxf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]
2026-08-07 Labels: fit-checked placement — text sized/oriented so its whole box clears every cut + hole
    - compute_label: run along long axis, binary-search largest height whose bounding box is verified
    inside the material and clear of all holes (was: sized from point-clearance -> overlapped)
    - ~13x faster label search; regenerate all sheets
    [sheet_01.dxf, sheet_02.dxf, sheet_04.dxf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]
2026-08-07 Rename (display map in config): 'Spur Gear 12 teeth'->'driven gear', 'Component19'->'Links h,i,g'
    - labels + BOM use display names; DXF files stay Fusion-named so re-exports still match
    - also applied to hole-role matching via source name (unchanged)
    [BOM.csv, sheet_01.dxf, sheet_02.dxf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]
2026-08-07 Crank: convex hull outline + 8mm crankshaft mount hole; 2 cranks on 1-kit sheet
    - Hull wraps the oversized 25mm hub feature so the crank outline no longer
    self-intersects (config: hull_parts).
    - The wrapped hub circle is replaced by an 8mm through-hole (friction fit on
    the 8mm crankshaft rod) instead of surviving as a 150mm cut circle.
    - qty_override adds a 2nd crank into the spare space on the one-beest sheet.
    - BOM: crank mount listed under the 8mm friction holes.
    [BOM.csv, sheet_01.dxf, sheet_02.dxf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]
2026-08-07 Re-render one-beest sheet preview to match corrected crank DXF
    nested_1kit/sheet_01.svg was rendered before the crank hub fix, so it still
    showed the old 150mm circle even though the DXF cut file was already the
    merged single-outline crank. Re-rendered from the current DXF.
2026-08-07 Add pre-cut build risk review (audit + materials/Snijlab research)
    13 ranked risks with fixes: Snijlab sheet-size mismatch (2440x1220 vs
    1200x1200 birch stock), cut/engrave colour+format convention, uncompensated
    kerf, 606-bearing over-engineering + retention, single-layer link stiffness,
    gear-mesh/Component19 verification, crankshaft flex, feet traction, phasing.
2026-08-07 Snijlab-ready output: 1200x1200 nesting, kerf comp, blue/red layers, DXF R2004
    - Re-nest to Snijlab's 1200x1200 birch stock (6 kits -> 13 sheets; 1 kit -> 3).
    - Kerf compensation (kerf_mm, default 0.2): every hole shrunk one kerf so
    fits land right (verify exact value with a coupon).
    - Snijlab colour/format: cut -> blue 'cut' layer RGB(0,0,255); labels -> red
    'line engraving' layer RGB(255,0,0); label text converted to outline
    polylines (no TEXT); saved as DXF R2004, mm.
    - BUILD_RISKS.md: mark R1/R2/R3 fixed. BOM: 13x 1200x1200 birch sheets.
    [BOM.csv, sheet_01.dxf, sheet_02.dxf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]
2026-08-08 Drop to crankshaft-only bearings: 606 -> 30, leg pivots become M8+washers
    - default_hole_mm 22 -> 9: leg-link holes are now M8 pivot-clearance holes;
    22mm 608 seats kept only on the crankshaft supports (frame spacer, spacer).
    - Friction math shows plain bolt pivots are ~0.4 kgf at the crank; saves ~€215
    and removes the plywood bearing-retention problem.
    - BOM: 30 bearings, three hole sizes (22 bearing / 9 pivot / 8 friction),
    anti-bind bushing tip, updated totals (~€450-650 for 6 kits).
    - BUILD_RISKS: R4 fixed; R8 "Links h,i,g is one part" confirmed by user.
    [BOM.csv, sheet_01.dxf, sheet_02.dxf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]
2026-08-08 README: link the one-beest build; fix stale sheet counts + cut/engrave note
    - Prominent link to nested_1kit (one complete beest = 3 sheets) as the start point.
    - Correct output/demo to 13 sheets; point to BUILD_RISKS.md.
    - Update the after-nesting note to the Snijlab blue-cut/red-engrave convention.
2026-08-08 Add label-free one-beest build (nested_1kit_nolabel) for cut-cost testing
    config_1kit_nolabel.json sets label_height_mm=0 -> no engraving layer/paths,
    just blue cut geometry. Same 3 sheets, R2004, kerf + crankshaft-only holes.
    Drops the ~16m of engraving path from one beest for a cheaper/faster cut test.
    [BOM.csv, sheet_01.dxf, sheet_02.dxf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]
2026-08-08 Add ~1.5m single showpiece beest build (9x scale) for quoting
    config_1beest_1p5m.json: scale 9.0, one beest, 5 sheets of 1200x1200.
    Longest part 764mm (fits Snijlab bed). ~108m total path (~1/4 of the 6-kit
    plan). Holes unchanged (8/9/22mm hardware); crankshaft-only bearings; labels on.
    [BOM.csv, Component19.dxf, LinkB.dxf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]
2026-08-08 1.5m beest: double the 4 long links (E, J, K, Links h,i,g) for stiffness
    qty_override 6->12 on the long links so each is laminated (glue 2x into one
    solid 18mm member, not 4 loose layers). 7 sheets, ~156m path (~EUR1030).
    [BOM.csv, Component19.dxf, LinkB.dxf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]
2026-08-08 1.5m beest: 10mm central crankshaft + 6900 bearings
    - hole_roles: driven-gear centre bore 8->10 (keyed to the central crankshaft).
    Crank-pin hole stays 8mm; 22mm bearing seats unchanged (6900 has 22mm OD).
    - 1.5m config hardware: 6900ZZ (10x22x6) x5, 10mm central rod, side shafts +
    everything else stay 8mm.
    - Note: waist-height builds keep 8mm centre until re-run (they share hole_roles).
    [BOM.csv, Component19.dxf, LinkB.dxf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]
2026-08-08 1.5m beest: crank mount bore 8->10 (crank keyed to central 10mm shaft)
    Crank handle hole stays 8mm. Confirms central-shaft parts: driven-gear centre
    + crank mount = 10mm; spacer/frame-spacer 22mm seats unchanged (6900 bearings).
    [Component19.dxf, LinkB.dxf, LinkC.dxf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]
2026-08-08 1.5m beest: kerf_mm 0.2 -> 0 (draw holes at true nominal = generous fits)
    Holes now cut ~0.2mm oversize (loose), never tight -> no sanding on the 96 leg
    pivots, robust to kerf variation. Glue/pin the ~10 grip fits (gear/crank on
    shaft, bearings) instead. Makes the coupon optional for the EUR700 cut.
    [Component19.dxf, LinkB.dxf, LinkC.dxf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]
